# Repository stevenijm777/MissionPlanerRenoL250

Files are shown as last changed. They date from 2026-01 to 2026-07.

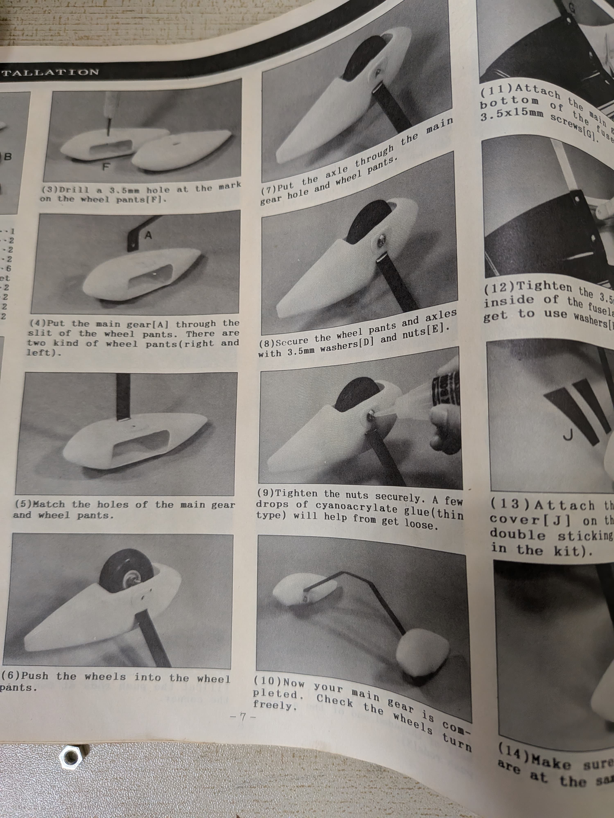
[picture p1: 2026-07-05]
Manual_RENOL250/WhatsApp Image 2025-07-14 at 20.57.17_f2a60a2f.jpg

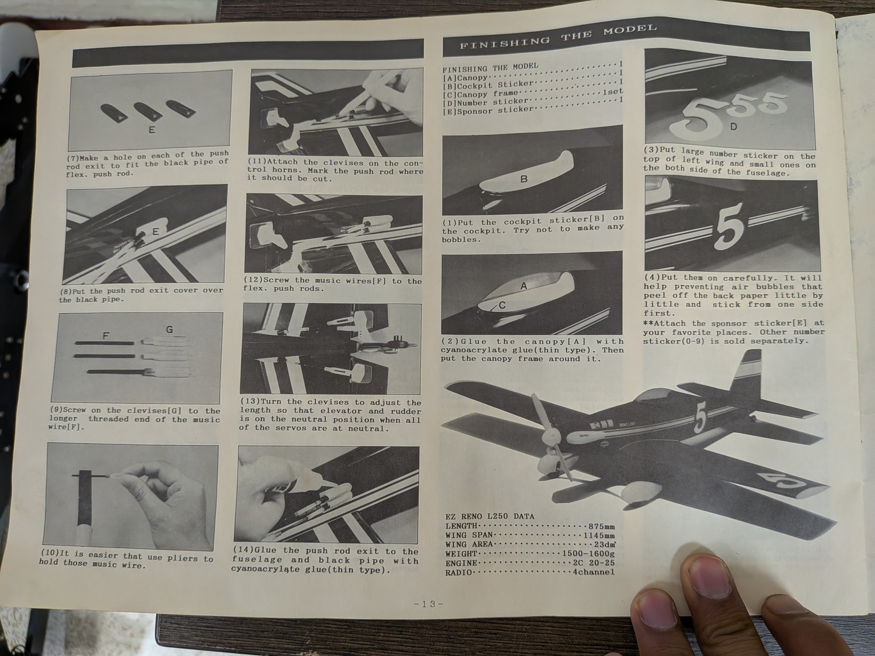
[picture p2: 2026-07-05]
Manual_RENOL250/WhatsApp Image 2025-07-14 at 20.57.13_8dc4a4ed.jpg

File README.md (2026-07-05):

# Mission Planner & Integración Mecatrónica - Reno L250 UAV

Este repositorio contiene los archivos de software, diseño mecánico CAD 3D, planos de fabricación, parámetros del piloto automático y scripts de análisis de telemetría utilizados en el proyecto de titulación y artículo de investigación: **"Integración mecatrónica y validación de una plataforma UAV de ala fija de bajo costo basada en arquitectura abierta"** (ESPOL).

El enfoque de este repositorio está orientado a la plataforma comercial **Reno L250** convertida de combustión interna a propulsión eléctrica pura para investigación en vuelo autónomo.

---

## 🔗 Repositorio de Simulación (Gemelo Digital)
Para complementar las pruebas en hardware físico con simulaciones de alta fidelidad, se ha desarrollado un Gemelo Digital en **NVIDIA Isaac Sim** empleando **Pegasus Simulator**. 
* El repositorio con el script de simulación de la planta aerodinámica y el entorno 3D está disponible en: [isaac-uav (GitHub)](https://github.com/stevenijm777/isaac-uav)
* Ruta local para contexto: `C:\Users\steve\Documents\GitRepositories\isaac-uav`

---

## 📂 Estructura del Repositorio

El repositorio se organiza de la siguiente manera:

```text
MissionPlanerRenoL250/
├── 12_Codigos_Graficas/   # Jupyter Notebook y scripts de Python para procesamiento de logs .BIN
├── Calculos/              # Hoja de cálculo verificada de diseño dinámico e importación
├── Manual_RENOL250/       # Escaneos del manual físico de ensamblaje del Reno L250
├── Modelo3D/              # Archivos CAD Autodesk Inventor (.ipt, .iam), STLs impresiones y planos PDF
├── Parametros/            # Archivos de respaldo de parámetros (.param) de ArduPilot
├── Guia_Mission_Planner.pdf # Guía de integración de software y hardware
└── .gitignore             # Configuración de exclusión para logs pesados y temporales CAD
```

### 1. `12_Codigos_Graficas/`
Contiene la algoritmia para análisis post-vuelo de telemetría y vibraciones:
* **`processVibe.py`**: Script en Python para extraer datos del mensaje `VIBE` del log de vuelo `.BIN` y generar gráficas de vibraciones en los ejes X, Y y Z en alta resolución bajo normas APA.
* **`missionPlanning.ipynb`**: Jupyter Notebook interactivo que procesa la telemetría MAVLink para validar la respuesta de actuadores comparando las entradas del piloto (`RCIN`) frente a las salidas físicas de los servomotores (`RCOUT`) en los canales de guiñada, cabeceo, alabeo y acelerador.
* **Gráficas PNG**: Resultados exportados que muestran la supresión de vibraciones y la validación de latencia cero en la cadena de control.

### 2. `Calculos/`
* **`ANALISIS_COMPLETO_UAV.xlsx`**: Hoja de cálculo dinámica y verificada que consolida el análisis de pesos (MTOW) y estimación aerodinámica de los modelos Foam Board (Manual/Auto), Reno L250 y la variante de alta velocidad (2200KV). Permite calcular de manera automática:
  * Velocidad de pérdida ($V_{stall}$) y carga alar ($WL$) basándose en el coeficiente de sustentación $C_{L_{max}}$ y área alar de diseño.
  * Relación Empuje/Peso ($T/W$) y potencia requerida.
  * Autonomía teórica y práctica (70% de reserva).
  * Desglose completo de importación (FOB EE.UU. a Ecuador sumando aranceles, Fodinfa, fletes por peso y tasas de aduana).

### 3. `Manual_RENOL250/`
* Recopilación de imágenes escaneadas de las instrucciones físicas originales del fuselaje comercial Reno L250. Esencial para conocer la distribución espacial del ala, estabilizadores, y las distancias de montaje recomendadas de fábrica.

### 4. `Modelo3D/`
* **`RenoL250/`**: Modelado 3D en Autodesk Inventor de la aeronave desglosado en ensambles (`.iam`) y partes (`.ipt`) de las alas, fuselaje principal (body), rudder, estabilizador vertical y tren de aterrizaje.
* **`Soporte_Pixhawck/`** y **`MOTOR/`**: Planos CAD de los soportes amortiguados impresos en 3D para el controlador Pixhawk 2.4.8 y el acople de conversión al motor eléctrico KingVal 3548.
* **`STL_Impresion/`**: Archivos `.stl` listos para laminación e impresión en 3D (PLA/PETG) de los soportes de servos, soportes del motor, llantas y trompa protectora.
* **`Planos_PDF_estructura/`**: Planos bidimensionales detallados con acotaciones mecánicas para la fabricación física y de taller.

### 5. `Parametros/`
* Archivos `.param` exportados desde Mission Planner. Incluyen la sintonización de lazos de control PID, límites operacionales de alabeo y cabeceo, configuración de canales PWM y calibración de sensores inerciales del UAV para ArduPilot.

---

##  Requisitos e Instalación

Para ejecutar los scripts de procesamiento de telemetría, se requiere Python 3.8+ y las siguientes dependencias:

```bash
pip install pymavlink pandas matplotlib openpyxl
```

### Ejecutar el análisis de vibraciones:
1. Copia tu archivo de log `.BIN` descargado de la tarjeta MicroSD de la Pixhawk en la carpeta de tu script.
2. Modifica la variable `log_file` en `processVibe.py` apuntando a tu archivo de log (ej. `log_file = '00000009.BIN'`).
3. Ejecuta el script:
   ```bash
   python 12_Codigos_Graficas/processVibe.py
   ```
4. Se generará una gráfica llamada `grafica_vibraciones_apa.png` mostrando la respuesta dinámica de aceleración inercial en $m/s^2$ (umbral seguro Pixhawk: $<30\text{ m/s}^2$).

---

##  Componentes de la Plataforma Reno L250 (Auto)
* **Controlador de Vuelo**: Pixhawk 2.4.8 (Firmware ArduPlane)
* **Módulo GNSS**: NEO-M8N GPS con brújula magnetómetro externa
* **Motor Brushless**: KingVal 3548 1100KV (Conversión eléctrica)
* **ESC (Speed Controller)**: Flycolor 60A ESC (3-6S Lipo)
* **Hélice**: 12x6 pulgadas de madera/nylon
* **Servomotores**: MG996R con engranajes metálicos de torque alto (3 unidades)
* **Batería**: LiPo 3S 2200 mAh (11.1 V)
* **Radiocontrol**: Transmisor Flysky FS-i6X y receptor FS-iA10B (2.4 GHz, 10 Canales)
* **Módulo de Poder (PMU)**: Sensor de corriente y regulador de voltaje 5.3V BEC

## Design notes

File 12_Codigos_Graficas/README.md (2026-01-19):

# MissionPlanerRenoL250
El código fuente para el controlador de vuelo Pixhawk, scripts de simulación y otros archivos de software se encuentran en el siguiente repositorio de GitHub.

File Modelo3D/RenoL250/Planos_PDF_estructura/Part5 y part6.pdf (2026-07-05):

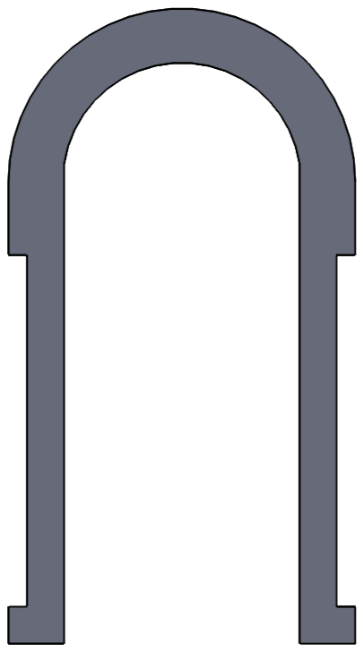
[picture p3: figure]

SOLIDWORKS Educational Product. For Instructional Use Only.

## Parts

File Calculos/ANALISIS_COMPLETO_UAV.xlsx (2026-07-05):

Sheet: DESEMPENO_UAV
ANÁLISIS DE DESEMPEÑO DE PLATAFORMAS UAV
Simbología | Características | Foam Board (Manual) | Foam Board (Auto) | Reno L250 (Auto) | Foam Board (2200KV Variant)
1. DATOS FÍSICOS Y GEOMETRÍA (ENTRADAS CAD)
b | Envergadura (m) | 1.050 m | 1.058 m | 1.143 m | 1.058 m
S | Área Alar (m²) | 0.1699 m² | 0.1699 m² | 0.2300 m² | 0.1699 m²
L | Longitud aproximada (m) | 0.800 m | 0.810 m | 0.880 m | 0.810 m
c | Cuerda media (MAC, m) | 0.155 m | 0.155 m | 0.201 m | 0.155 m
AR | Relación de Aspecto (Aspect Ratio) | 6.49 | 6.59 | 5.68 | 6.59
2. SISTEMA DE PROPULSIÓN Y BATERÍA (ENTRADAS ESPECIFICACIONES)
- | Modelo del Motor Brushless | A2212 1000KV | A2212 1000KV | KingVal 3548 1100KV | 2206 2200KV
- | Variador de velocidad (ESC) | ESC 30A | ESC 30A | ESC 60A | ESC 30A
- | Hélice seleccionada | 10x4.5 | 10x4.5 | 12x6 | 5x4.5
Vbatt | Voltaje nominal de batería (V) | 11.1 V | 11.1 V | 11.1 V | 11.1 V
C | Capacidad de la batería (Ah) | 2.2 Ah | 2.2 Ah | 2.2 Ah | 2.2 Ah
E | Energía total nominal (Wh) | 24.42 Wh | 24.42 Wh | 24.42 Wh | 24.42 Wh
Tkg | Empuje máximo estático (kg) | 0.885 kg | 0.885 kg | 2.218 kg | 1.020 kg
I_cruise | Corriente promedio en crucero (A) | 10.0 A | 10.0 A | 20.0 A | 17.0 A
I_max | Corriente en máxima aceleración (A) | 20.0 A | 20.0 A | 42.0 A | 25.0 A
I_elec | Consumo electrónica + servos (A) | 1.1 A | 1.1 A | 4.0 A | 1.1 A
3. CONSTANTES OPERATIVAS Y LÍMITES
g | Aceleración de gravedad (g, m/s²) | 9.81 m/s² | 9.81 m/s² | 9.81 m/s² | 9.81 m/s²
ρ | Densidad del aire (mar, ISA, kg/m³) | 1.225 kg/m³ | 1.225 kg/m³ | 1.225 kg/m³ | 1.225 kg/m³
CLmax | Coeficiente de Sustentación máximo | 0.90 | 0.90 | 1.20 | 0.90
CL_CFD | Coeficiente sustentación pérdida (CFD) | 0.90 | 0.90 | N/A | 0.90
4. ANÁLISIS DINÁMICO Y DESEMPEÑO CALCULADO
m | Masa total al despegue (MTOW, kg) | 0.582 kg | 0.644 kg | 1.600 kg | 0.619 kg
W | Peso total estimado (W, N) | 5.71 N | 6.32 N | 15.70 N | 6.07 N
Vstall | Velocidad de pérdida de diseño (m/s) | 7.81 m/s | 8.21 m/s | 9.64 m/s | 8.05 m/s
Vstall_k | Velocidad de pérdida de diseño (km/h) | 28.11 km/h | 29.57 km/h | 34.69 km/h | 28.99 km/h
Vstall_CFD | Velocidad de pérdida según CFD (m/s) | 7.81 m/s | 8.21 m/s | N/A | 8.05 m/s
WL | Carga Alar de Operación (g/dm²) | 34.3 g/dm² | 37.9 g/dm² | 69.6 g/dm² | 36.4 g/dm²
T/W_max | Relación Empuje/Peso Máxima | 1.52 | 1.37 | 1.39 | 1.65
t_th | Autonomía Teórica en crucero (min) | 11.9 min | 11.9 min | 5.5 min | 7.3 min
t_pr | Autonomía Práctica en crucero (70%, min) | 8.3 min | 8.3 min | 3.8 min | 5.1 min
t_th_max | Autonomía Teórica al 100% Throttle (min) | 6.3 min | 6.3 min | 2.9 min | 5.1 min
t_pr_max | Autonomía Práctica al 100% Throttle (min) | 4.4 min | 4.4 min | 2.0 min | 3.5 min
P_cruise | Potencia requerida en crucero (W) | 111.0 W | 111.0 W | 222.0 W | 188.7 W
P_max | Potencia máxima de propulsión (W) | 222.0 W | 222.0 W | 466.2 W | 277.5 W
V_cruise_rec | Velocidad de crucero recomendada (m/s) | 10.15 m/s | 10.68 m/s | 12.53 m/s | 10.47 m/s
- | Costo total importado (USD) | $234.04 | $586.62 | $1080.16 | $593.24

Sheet: MATERIALES_USA
DESGLOSE DE COSTOS Y ANÁLISIS DE IMPORTACIÓN (FOB EE.UU.)
Componente | Especificaciones | Manual Qty | W Unit Manual (g) | W Total Manual (g) | P Unit Manual (USD) | P Total Manual (USD) | Auto Qty | W Unit Auto (g) | W Total Auto (g) | P Unit Auto (USD) | P Total Auto (USD) | Reno Qty | W Unit Reno (g) | W Total Reno (g) | P Unit Reno (USD) | P Total Reno (USD) | Variant Qty | W Unit Variant (g) | W Total Variant (g) | P Unit Variant (USD) | P Total Variant (USD) | Referencia Link
Fuselaje / Estructura | Madera balsa / Foam board según plataforma | 1 | 236.00 g | 236.00 g | $8.00 | $8.00 | 1 | 166.45 g | 166.45 g | $8.00 | $8.00 | 1 | 600.00 g | 600.00 g | $260.00 | $260.00 | 1 | 166.45 g | 166.45 g | $8.00 | $8.00 | https://www.joyplanes.com/es/joytrainer-mini/
Motor Brushless | A2212 1000KV / KingVal 3548 1100KV / 2206 2200KV | 1 | 50.00 g | 50.00 g | $12.00 | $12.00 | 1 | 50.00 g | 50.00 g | $12.00 | $12.00 | 1 | 172.08 g | 172.08 g | $40.00 | $40.00 | 1 | 35.00 g | 35.00 g | $18.00 | $18.00 | https://a.co/d/4o5VnrM
Variador de Velocidad (ESC) | ESC 30A (manual/auto/variant) / Flycolor 60A (Reno) | 1 | 30.00 g | 30.00 g | $10.00 | $10.00 | 1 | 30.00 g | 30.00 g | $10.00 | $10.00 | 1 | 100.00 g | 100.00 g | $35.00 | $35.00 | 1 | 30.00 g | 30.00 g | $10.00 | $10.00 | https://www.amazon.com/dp/B09PNFKH23
Hélice de Diseño | 10x4.5 (Foam) / 12x6 (Reno) / 5x4.5 (Variant) | 1 | 15.00 g | 15.00 g | $5.00 | $5.00 | 1 | 15.00 g | 15.00 g | $5.00 | $5.00 | 1 | 40.00 g | 40.00 g | $30.00 | $30.00 | 1 | 5.00 g | 5.00 g | $4.00 | $4.00 | https://a.co/d/cJSaEcq
Batería LiPo 3S | Lipo 3S 2200 mAh (11.1 V) | 1 | 200.00 g | 200.00 g | $20.00 | $20.00 | 1 | 200.00 g | 200.00 g | $20.00 | $20.00 | 1 | 200.00 g | 200.00 g | $20.00 | $20.00 | 1 | 200.00 g | 200.00 g | $20.00 | $20.00 | https://www.amazon.com/dp/B077P73SDS
Servomotores | 9g estándar (Foam) / MG996R metal gear (Reno) | 4 | 9.00 g | 36.00 g | $2.50 | $10.00 | 4 | 9.00 g | 36.00 g | $2.50 | $10.00 | 3 | 60.00 g | 180.00 g | $10.00 | $30.00 | 4 | 9.00 g | 36.00 g | $2.50 | $10.00 | https://www.amazon.com/s?k=MG996R
Controlador de Vuelo | Pixhawk 2.4.8 Autopilot | 0 | 0.00 g | 0.00 g | $0.00 | $0.00 | 1 | 50.00 g | 50.00 g | $200.00 | $200.00 | 1 | 50.00 g | 50.00 g | $200.00 | $200.00 | 1 | 50.00 g | 50.00 g | $200.00 | $200.00 | https://www.amazon.com/dp/B07CHQ7SZ4
Módulo GPS / GNSS | NEO-M8N GPS con soporte antena | 0 | 0.00 g | 0.00 g | $0.00 | $0.00 | 1 | 20.00 g | 20.00 g | $40.00 | $40.00 | 1 | 20.00 g | 20.00 g | $40.00 | $40.00 | 1 | 20.00 g | 20.00 g | $40.00 | $40.00 | https://www.aliexpress.com/item/3256802594266311.html
Receptor Radiocontrol | Flysky FS-iA6B / FS-iA10B (2.4 GHz) | 1 | 15.00 g | 15.00 g | $24.00 | $24.00 | 1 | 15.00 g | 15.00 g | $24.00 | $24.00 | 1 | 15.00 g | 15.00 g | $24.00 | $24.00 | 1 | 15.00 g | 15.00 g | $24.00 | $24.00 | https://www.amazon.com/dp/B0744DPPL8
Transmisor Radiocontrol | Flysky FS-i6X (Estación Terrena - No embarcado) | 1 | 0.00 g | 0.00 g | $60.00 | $60.00 | 1 | 0.00 g | 0.00 g | $60.00 | $60.00 | 1 | 0.00 g | 0.00 g | $60.00 | $60.00 | 1 | 0.00 g | 0.00 g | $60.00 | $60.00 | https://www.amazon.com/dp/B0744DPPL8
Módulo de Alimentación (BEC) | Power Module 5.3V BEC con enchufe XT60 | 0 | 0.00 g | 0.00 g | $0.00 | $0.00 | 1 | 30.00 g | 30.00 g | $15.00 | $15.00 | 1 | 30.00 g | 30.00 g | $15.00 | $15.00 | 1 | 30.00 g | 30.00 g | $15.00 | $15.00 | https://www.amazon.com/dp/B06XFW1X3K
Acople impreso 3D | Soporte motor impreso PLA (en Reno) | 0 | 0.00 g | 0.00 g | $0.00 | $0.00 | 0 | 0.00 g | 0.00 g | $0.00 | $0.00 | 1 | 50.00 g | 50.00 g | $0.00 | $0.00 | 0 | 0.00 g | 0.00 g | $0.00 | $0.00 | Diseño Interno CAD (PLA)
Base interna impresa 3D | Base soporte baterías y Pixhawk (en Reno) | 0 | 0.00 g | 0.00 g | $0.00 | $0.00 | 0 | 0.00 g | 0.00 g | $0.00 | $0.00 | 1 | 80.00 g | 80.00 g | $0.00 | $0.00 | 0 | 0.00 g | 0.00 g | $0.00 | $0.00 | Diseño Interno CAD (PLA)
Otros (Tornillería, cables, velcro, pegamento, varillas) | Elementos varios para integración física | 1 | 0.00 g | 0.00 g | $0.00 | $0.00 | 1 | 31.55 g | 31.55 g | $0.00 | $0.00 | 1 | 62.92 g | 62.92 g | $0.00 | $0.00 | 1 | 272.55 g | 31.55 g | $0.00 | $0.00 | Material de taller local
SUBTOTALES (FOB EE.UU.) |  |  |  | 582.00 g |  | $149.00 |  |  | 644.00 g |  | $404.00 |  |  | 1600.00 g |  | $754.00 |  |  | 619.00 g |  | $409.00
ANÁLISIS DE COSTO DE IMPORTACIÓN A ECUADOR
Costo por Libra Courier ($/lb) |  |  |  | $5.00 |  |  |  |  | $5.00 |  |  |  |  | $5.00 |  |  |  |  | $5.00
Peso de Vuelo Total (lbs) |  |  |  | 1.28 lbs |  |  |  |  | 1.42 lbs |  |  |  |  | 3.53 lbs |  |  |  |  | 1.36 lbs
Costo por Flete (Costo Peso) |  |  |  | $6.42 |  |  |  |  | $7.10 |  |  |  |  | $17.64 |  |  |  |  | $6.82
Precio FOB en EE.UU. (USD) |  |  |  | $149.00 |  |  |  |  | $404.00 |  |  |  |  | $754.00 |  |  |  |  | $409.00
Envío Doméstico en EE.UU. (Shipping 12%) |  |  |  | $17.88 |  |  |  |  | $48.48 |  |  |  |  | $90.48 |  |  |  |  | $49.08
Impuesto Ventas EE.UU. (US Sales Tax 6%) |  |  |  | $8.94 |  |  |  |  | $24.24 |  |  |  |  | $45.24 |  |  |  |  | $24.54
Arancel de Importación (Adunas 15% FOB) |  |  |  | $22.35 |  |  |  |  | $60.60 |  |  |  |  | $113.10 |  |  |  |  | $61.35
FODINFA (5% FOB + $2.00 Fijo) |  |  |  | $9.45 |  |  |  |  | $22.20 |  |  |  |  | $39.70 |  |  |  |  | $22.45
Tasa Fija Courier (Aduana Ecu.) |  |  |  | $20.00 |  |  |  |  | $20.00 |  |  |  |  | $20.00 |  |  |  |  | $20.00
COSTO TOTAL IMPORTADO (USD) |  |  |  | $234.04 |  |  |  |  | $586.62 |  |  |  |  | $1080.16 |  |  |  |  | $593.24

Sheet: AERODINAMICA_CFD
CARACTERIZACIÓN AERODINÁMICA MEDIANTE CFD (SOLIDWORKS)
Coeficientes longitudinales del Foam Board (crucero constante V = 15 m/s, q = 137.81 Pa, S = 0.1699 m²)
Ángulo de Ataque (AoA, α) | Coeficiente Sustentación (CL) | Coeficiente Arrastre (CD) | Coeficiente Momento (Cm @ CG) | Eficiencia Aerodinámica (L/D)
0° | 0.008 | 0.155 | 0.057 | 0.05
5° | 0.245 | 0.104 | 0.039 | 2.36
10° | 0.459 | 0.128 | 0.107 | 3.59
15° | 0.719 | 0.244 | 0.119 | 2.95
20° | 0.900 | 0.367 | 0.174 | 2.45
DERIVADAS DE ESTABILIDAD Y COMPORTAMIENTO LONGITUDINAL
Pendiente de Sustentación (Linear CL_alpha) |  | CL_alpha | 2.710 rad⁻¹
Gradiente de Momento de Cabeceo (Cm_alpha) |  | Cm_alpha | -0.205 rad⁻¹
Margen Estático de Diseño (Static Margin, SM) |  | SM | #DIV/0!

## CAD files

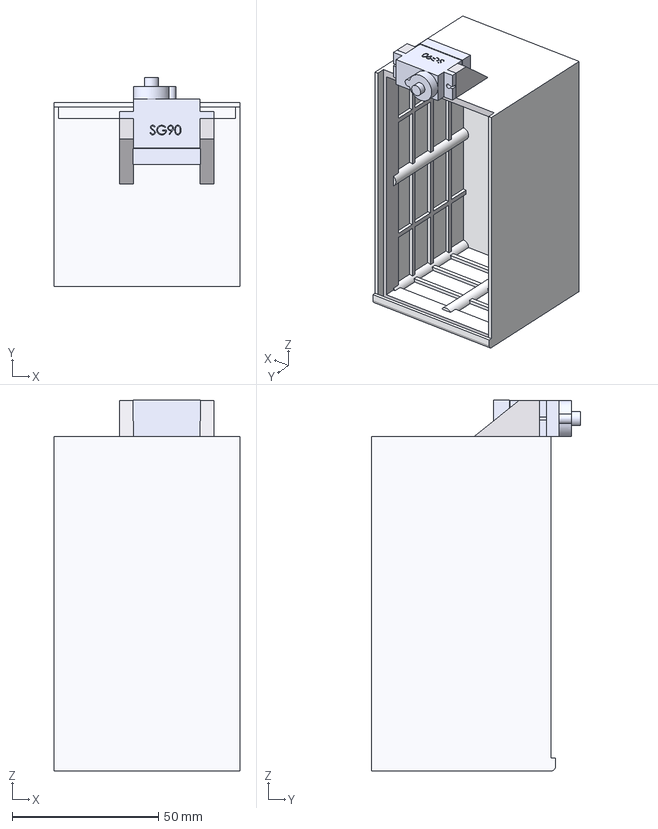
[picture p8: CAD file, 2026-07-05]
Modelo3D/Paracaidas/ParacaidasV2/Diseño de paracaidas/Diseño de paracaidas/Ensamble caja de paracaidas.stp
63.5 x 71.3 x 126.8 mm
sg90 micro servo
Caja sin ranura sin huecos

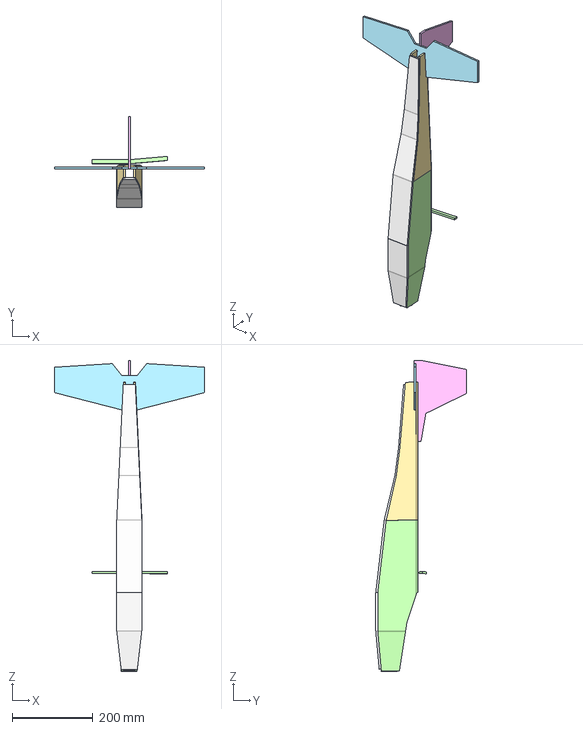
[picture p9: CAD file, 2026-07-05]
Modelo3D/CAD_SolidWorks/Avion_White/ENSAMBLE_Simplify_1.stp
372.5 x 224.1 x 770.0 mm

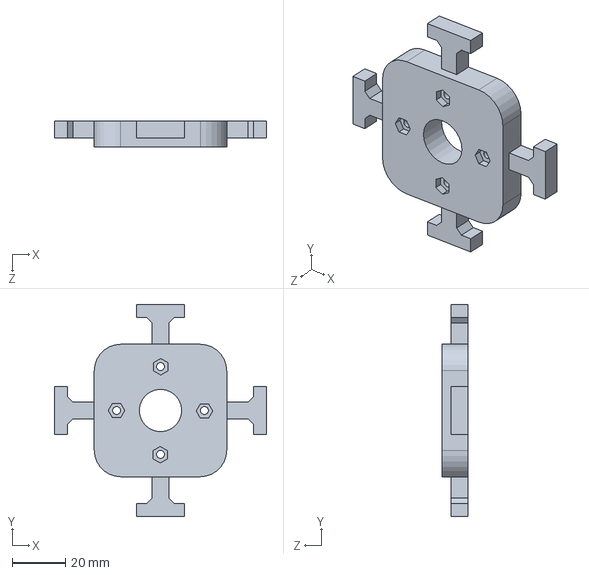
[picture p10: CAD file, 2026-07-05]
Modelo3D/CAD_SolidWorks/Avion_White/soporte_motor.SLDPRT
80.0 x 80.0 x 9.70 mm

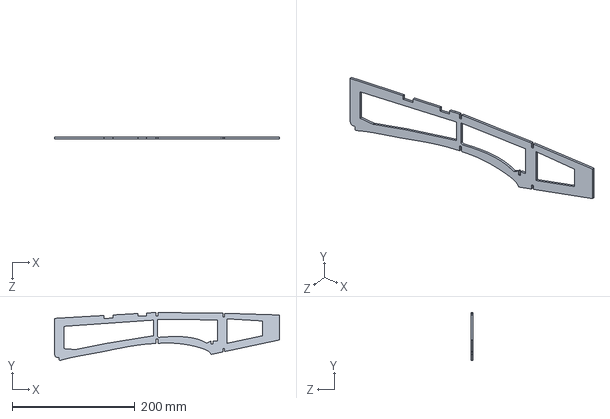
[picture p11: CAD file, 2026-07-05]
Modelo3D/CAD_SolidWorks/Piezas_Avion/fuselajev2.SLDPRT
366.8 x 78.5 x 3.00 mm

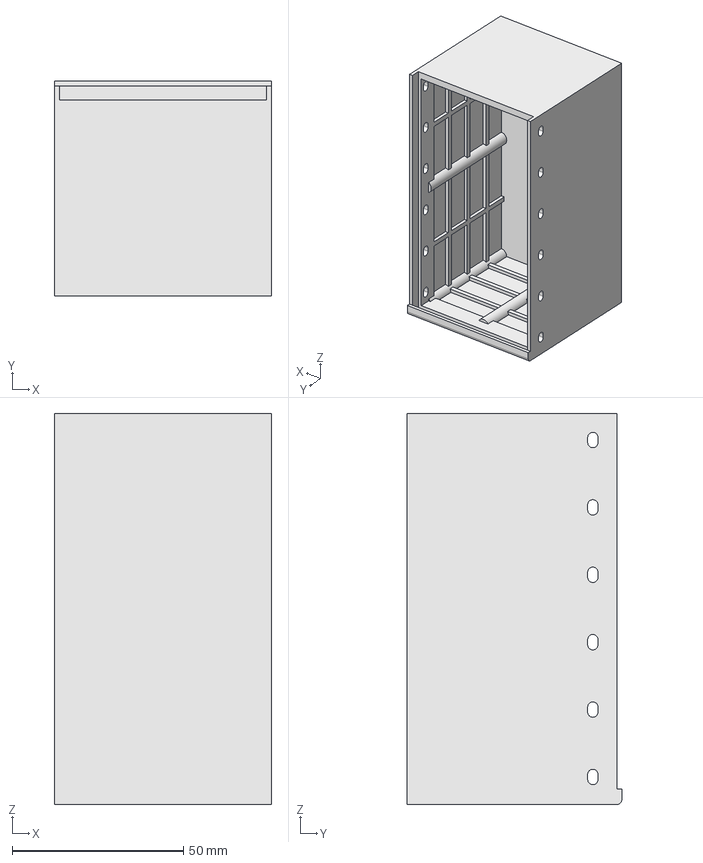
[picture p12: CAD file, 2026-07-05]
Modelo3D/Paracaidas/ParacaidasV2/Diseño de paracaidas/Diseño de paracaidas/Caja Paracaidas.stp
63.5 x 62.8 x 114.3 mm

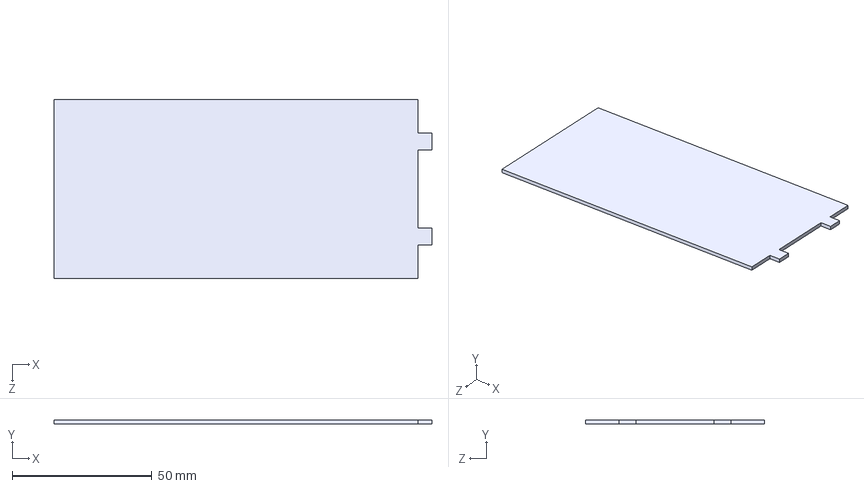
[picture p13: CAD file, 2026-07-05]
Modelo3D/Paracaidas/Tapa_Paracaidas.STEP
135.0 x 1.60 x 64.0 mm

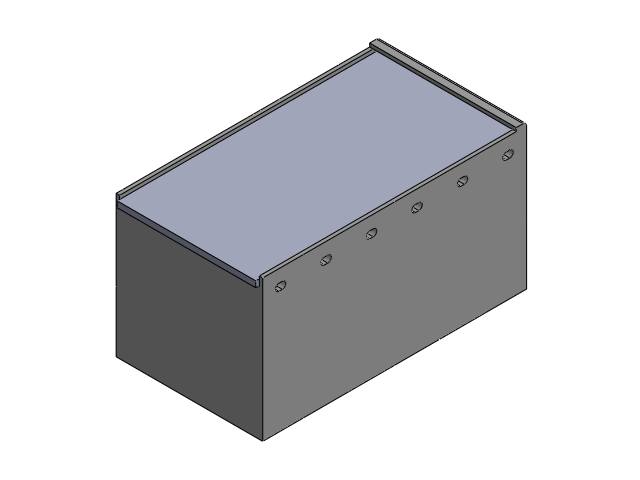
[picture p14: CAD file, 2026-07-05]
Modelo3D/Paracaidas/ParacaidasV2/Assem1.SLDASM
Caja Paracaidas
Tapa

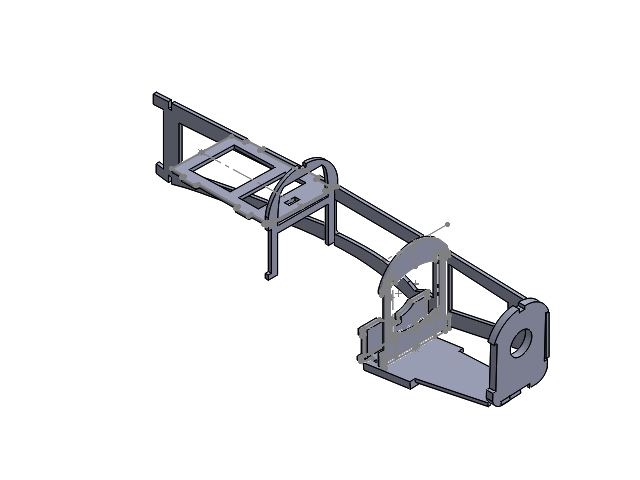
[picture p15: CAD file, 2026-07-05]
Modelo3D/CAD_SolidWorks/Piezas_Avion/esamb lev2.SLDASM
fuselajev3
soporte_servos
Soporte_motor

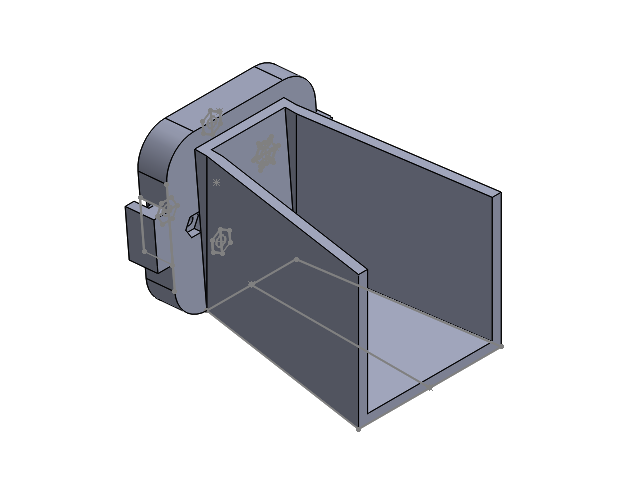
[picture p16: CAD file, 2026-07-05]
Modelo3D/CAD_SolidWorks/Avion_White/Assem1 2.SLDASM
trompa
soporte_motor_joelV2

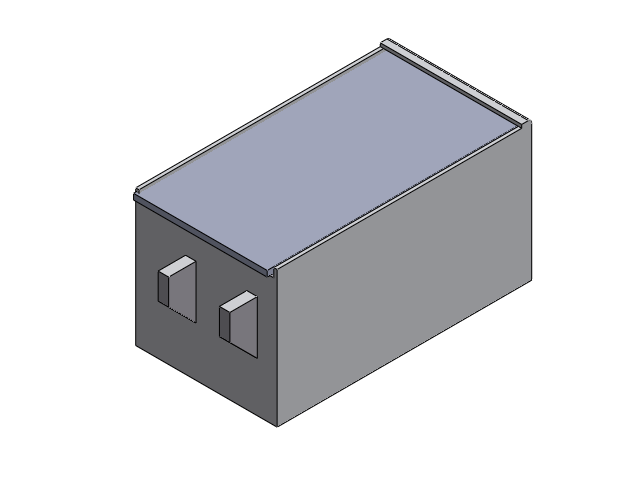
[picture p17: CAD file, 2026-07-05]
Modelo3D/Paracaidas/ParacaidasV2/Assem2.SLDASM
Caja sin ranura sin huecosV3.stp
Tapa

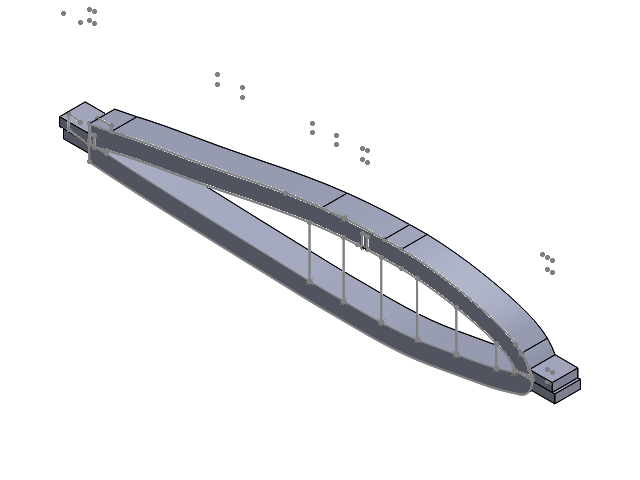
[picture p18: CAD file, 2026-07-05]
Modelo3D/CAD_SolidWorks/Piezas_Avion/esamble_Soperte.SLDASM
soporte_inferior
soporte_superior

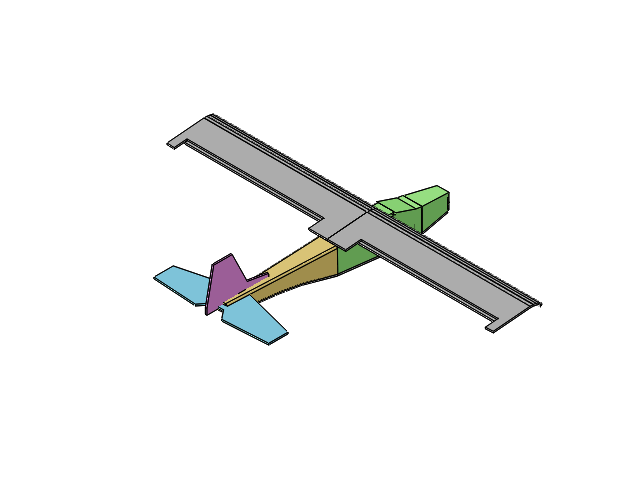
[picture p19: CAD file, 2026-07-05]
Modelo3D/CAD_SolidWorks/Avion_White/Assem1.SLDASM
ENSAMBLE_Simplify_1
ALA
ALA_MIR

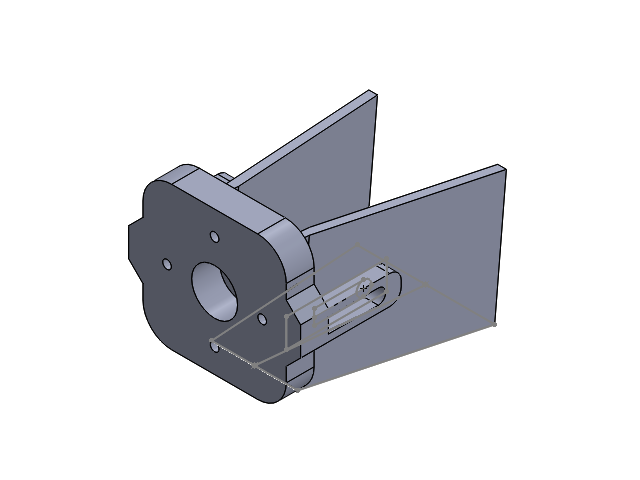
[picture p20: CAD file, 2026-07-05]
Modelo3D/CAD_SolidWorks/Avion_White/frente.SLDASM
soporte_motor_joel
trompa

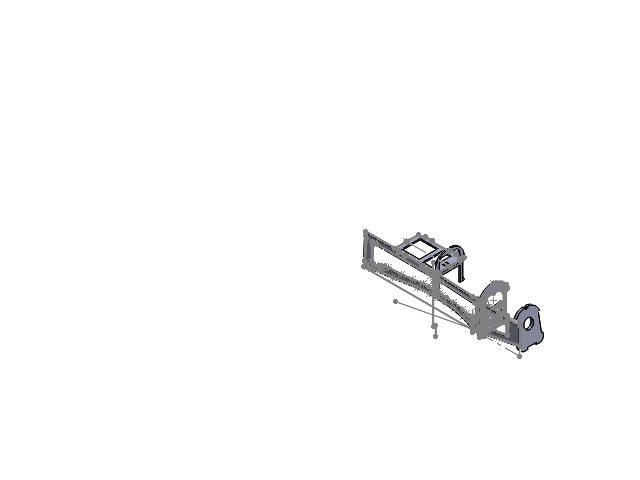
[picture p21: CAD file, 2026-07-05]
Modelo3D/CAD_SolidWorks/Piezas_Avion/esamble2.SLDASM
fuselaje
Soporte_motor
soporte_servos

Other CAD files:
Modelo3D/CAD_SolidWorks/Piezas_Avion/avion.SLDASM
Modelo3D/CAD_SolidWorks/Piezas_Avion/esmanel_soporte_agarre.SLDASM
Modelo3D/CAD_SolidWorks/Soporte_Plano.dwg
Modelo3D/Paracaidas/ParacaidasV2/Diseño de paracaidas/Diseño de paracaidas/Nueva carpeta/MARCOYCAJA.dwg
Modelo3D/CAD_SolidWorks/Avion_White/ALA.SLDPRT
Modelo3D/CAD_SolidWorks/Avion_White/ALA.stp
Modelo3D/CAD_SolidWorks/Avion_White/ALA_MIR.SLDPRT
Modelo3D/CAD_SolidWorks/Avion_White/ALA_MIR.stp
Modelo3D/CAD_SolidWorks/Avion_White/Ailerons.SLDPRT
Modelo3D/CAD_SolidWorks/Avion_White/ENSAMBLE_Simplify_1.SLDPRT
Modelo3D/CAD_SolidWorks/Avion_White/llanta_delantera.SLDPRT
Modelo3D/CAD_SolidWorks/Avion_White/llanta_trasera.SLDPRT
Modelo3D/CAD_SolidWorks/Avion_White/muelle.SLDPRT
Modelo3D/CAD_SolidWorks/Avion_White/soporte_motor_joel.SLDPRT
Modelo3D/CAD_SolidWorks/Avion_White/soporte_motor_joelV2.SLDPRT
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

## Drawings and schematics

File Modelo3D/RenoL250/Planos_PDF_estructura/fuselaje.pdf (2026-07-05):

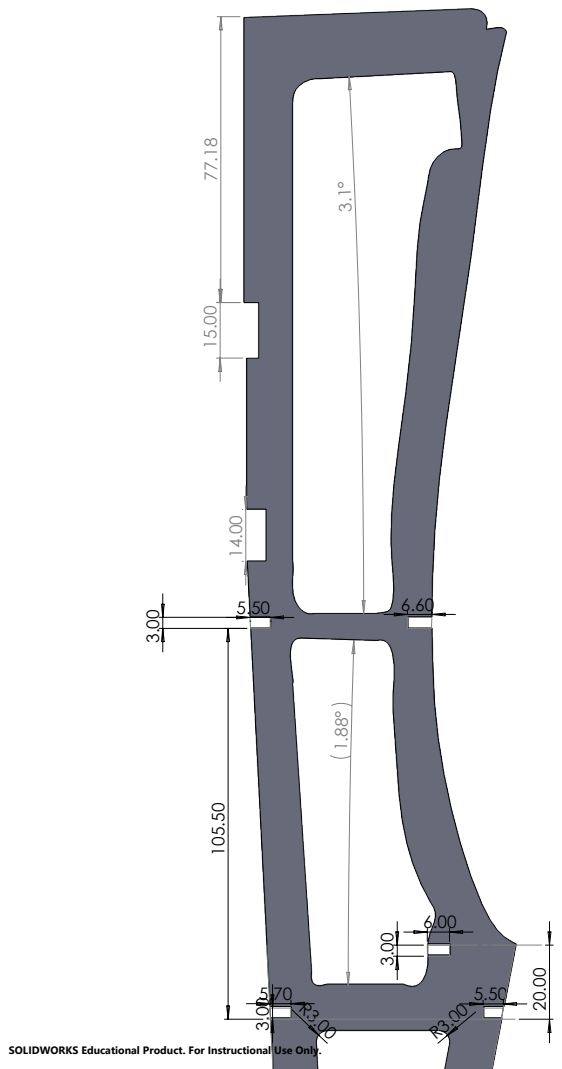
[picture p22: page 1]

SOLIDWORKS Educational Product. For Instructional Use Only.

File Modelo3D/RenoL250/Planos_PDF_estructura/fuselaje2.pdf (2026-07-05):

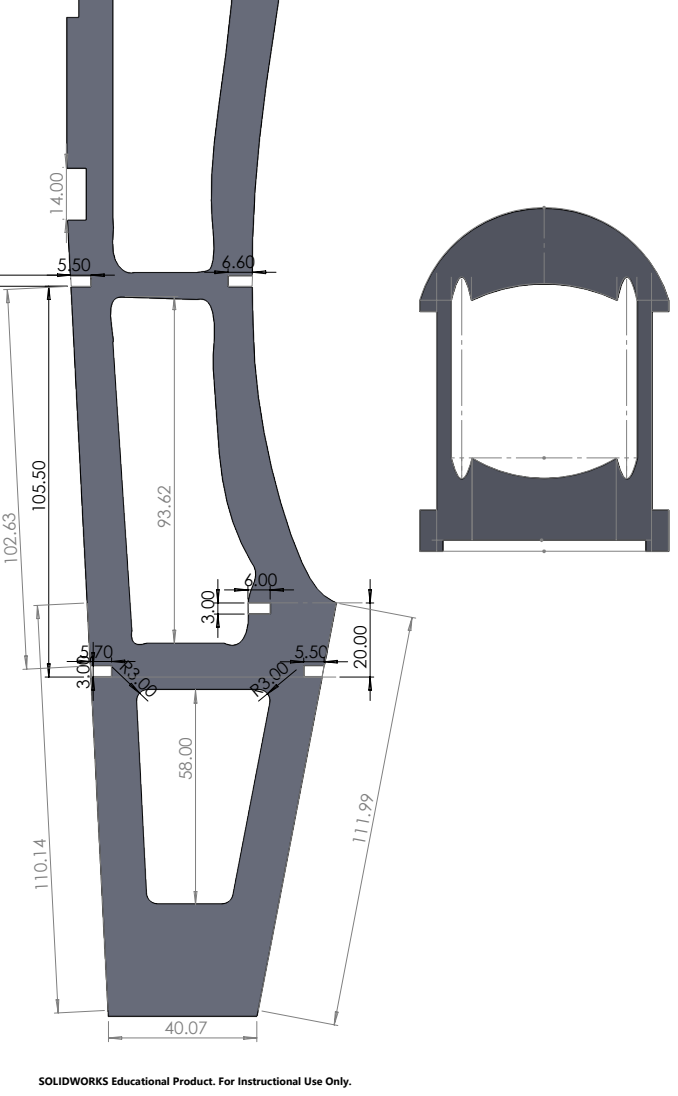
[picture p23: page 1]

SOLIDWORKS Educational Product. For Instructional Use Only.

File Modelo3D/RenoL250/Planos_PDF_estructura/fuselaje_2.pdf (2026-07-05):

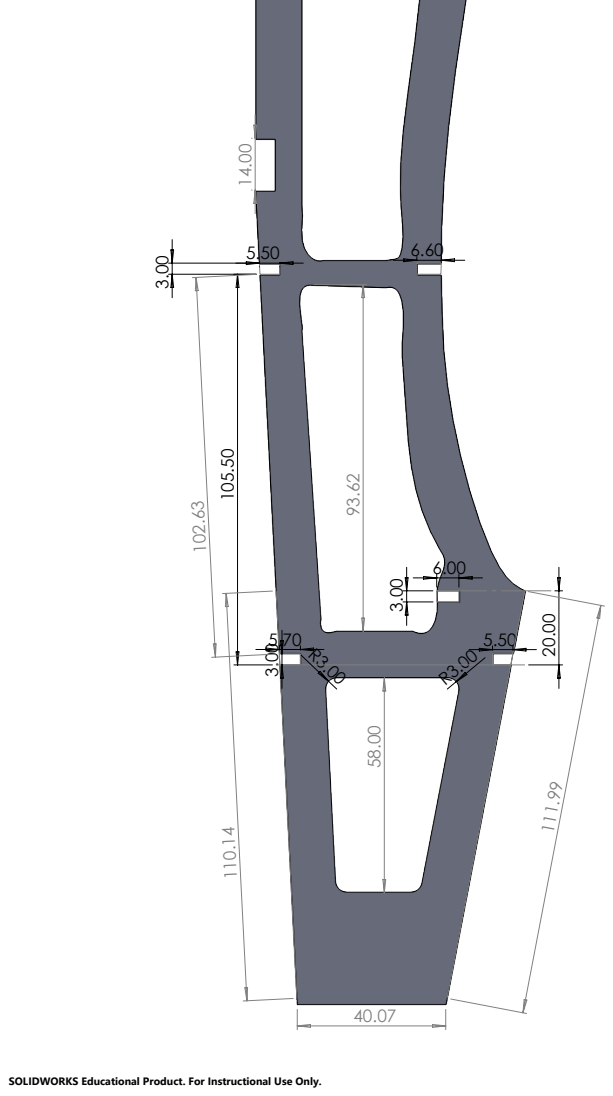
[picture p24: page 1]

SOLIDWORKS Educational Product. For Instructional Use Only.

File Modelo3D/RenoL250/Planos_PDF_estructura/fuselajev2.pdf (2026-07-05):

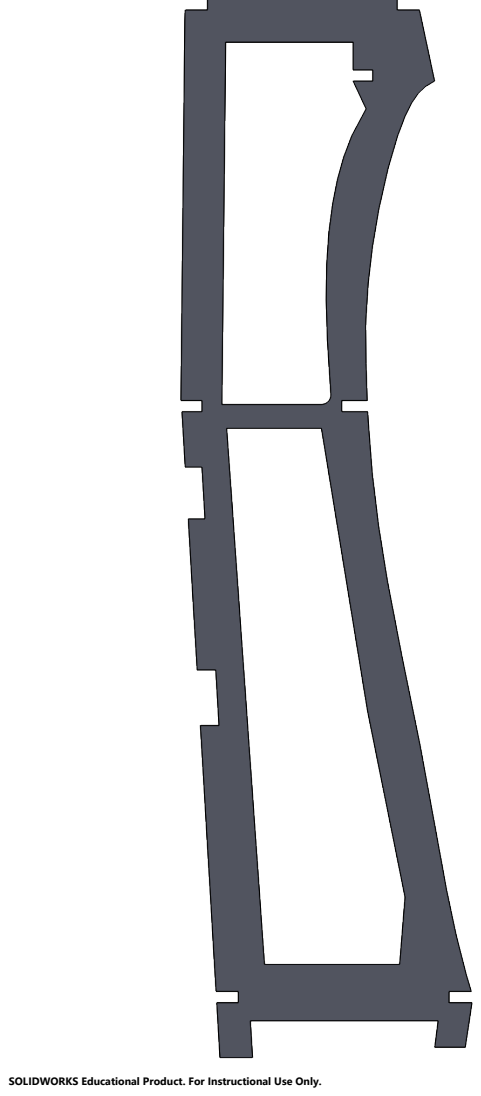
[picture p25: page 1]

SOLIDWORKS Educational Product. For Instructional Use Only.

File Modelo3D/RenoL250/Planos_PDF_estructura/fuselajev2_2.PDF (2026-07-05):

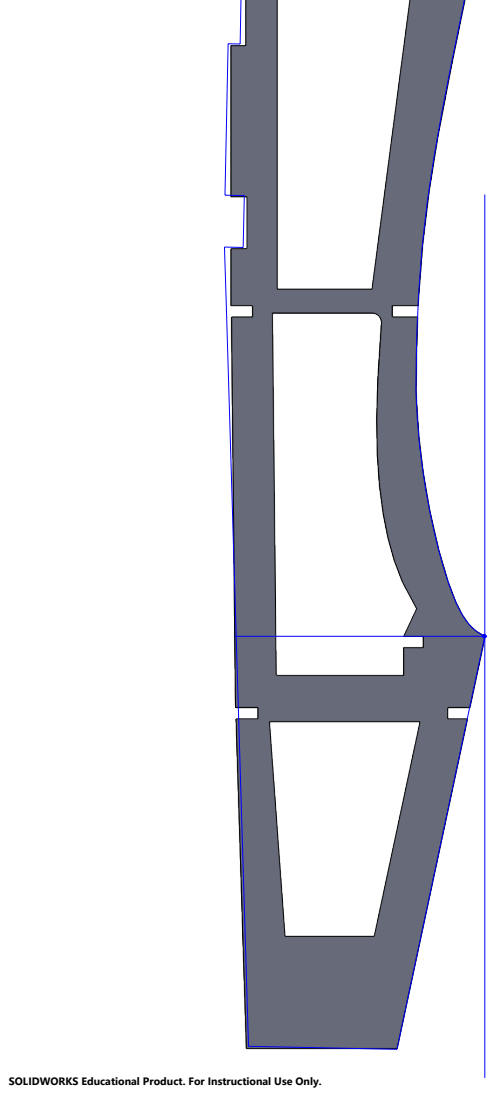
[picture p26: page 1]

SOLIDWORKS Educational Product. For Instructional Use Only.

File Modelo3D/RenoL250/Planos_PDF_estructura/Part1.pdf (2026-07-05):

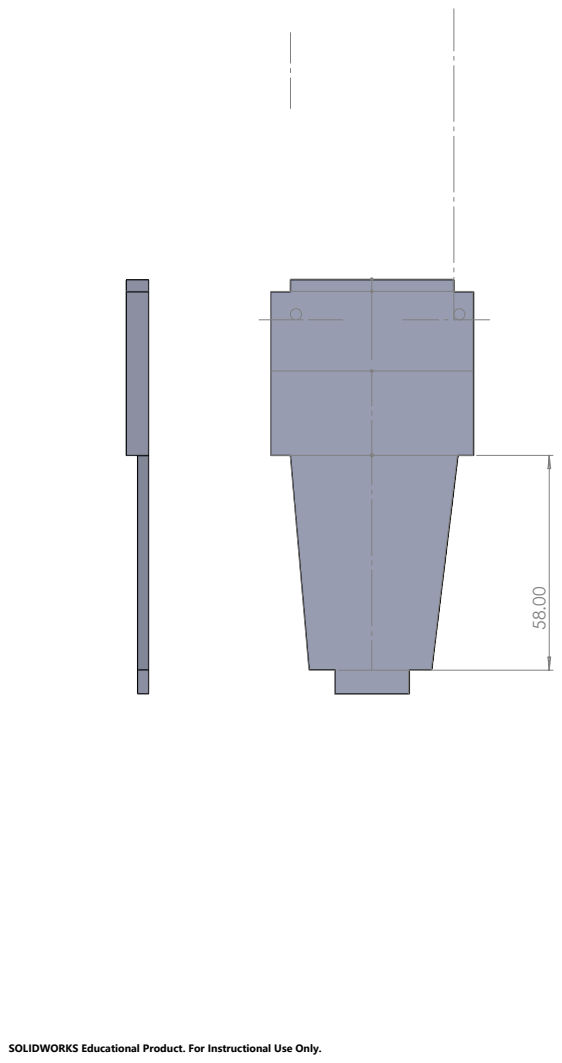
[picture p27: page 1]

SOLIDWORKS Educational Product. For Instructional Use Only.

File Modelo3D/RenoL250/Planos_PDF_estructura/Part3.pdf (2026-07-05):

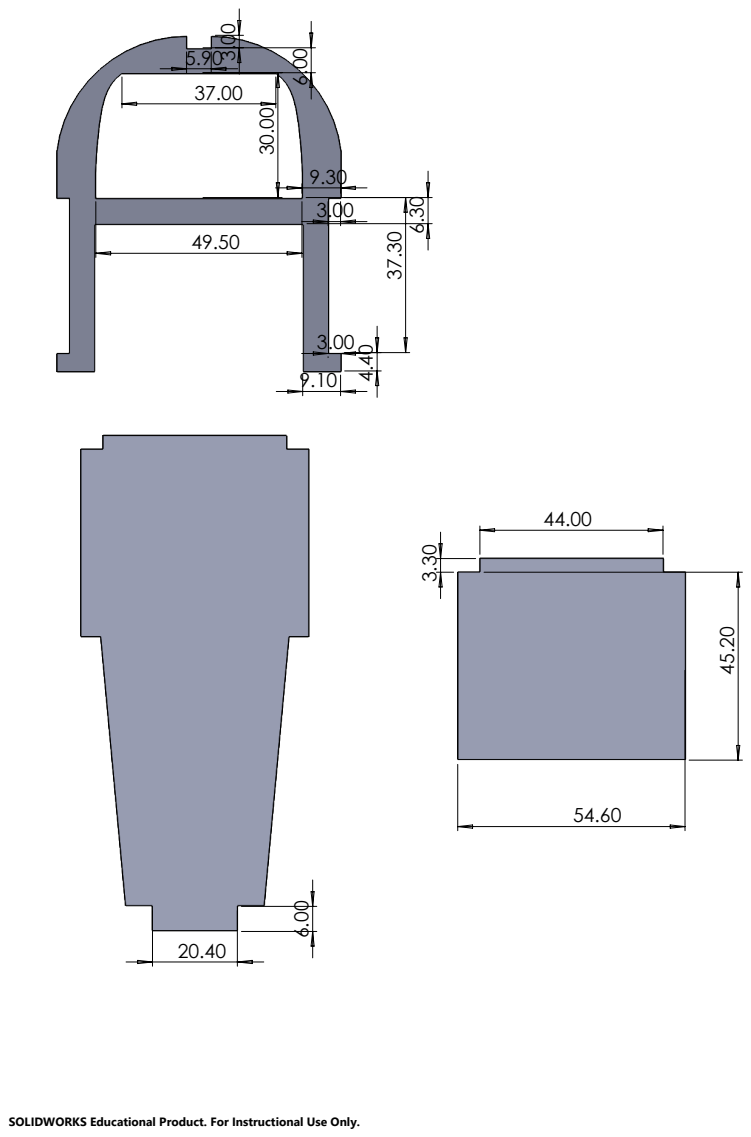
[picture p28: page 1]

SOLIDWORKS Educational Product. For Instructional Use Only.

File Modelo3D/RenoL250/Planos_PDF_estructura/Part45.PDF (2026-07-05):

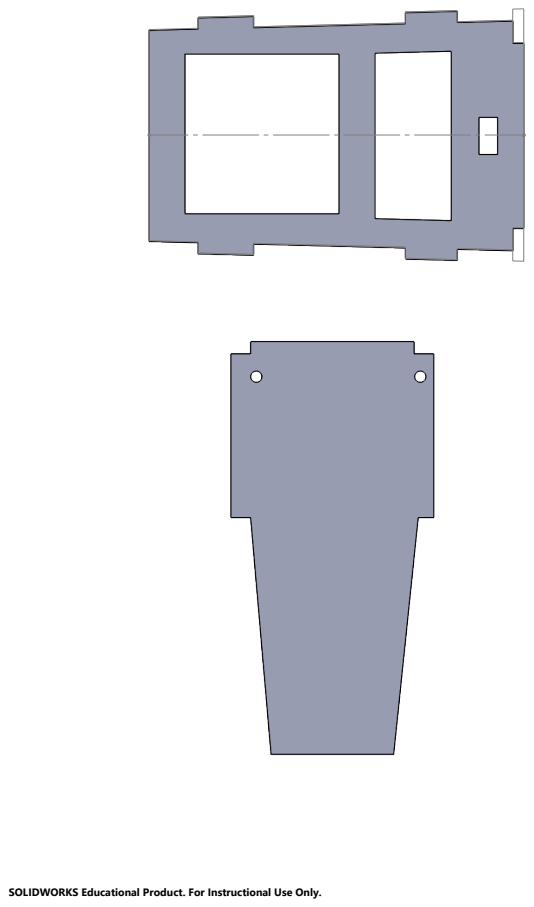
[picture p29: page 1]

SOLIDWORKS Educational Product. For Instructional Use Only.

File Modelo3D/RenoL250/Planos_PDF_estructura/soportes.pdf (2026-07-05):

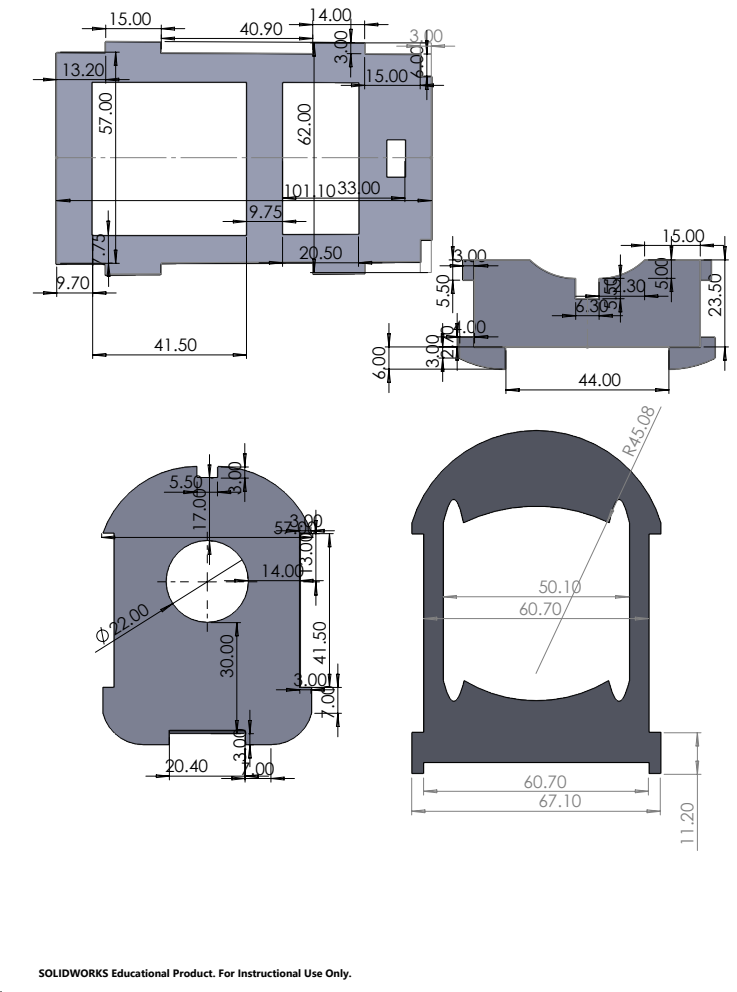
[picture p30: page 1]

SOLIDWORKS Educational Product. For Instructional Use Only.

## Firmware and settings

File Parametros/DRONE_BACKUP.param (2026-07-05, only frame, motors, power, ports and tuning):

ATC_ANG_LIM_TC,1
ATC_ANG_PIT_P,4.5
ATC_ANG_RLL_P,4.5
ATC_ANG_YAW_P,4.5
ATC_ANGLE_BOOST,1
ATC_RAT_PIT_D,0.0036
ATC_RAT_PIT_D_FF,0
ATC_RAT_PIT_FF,0
ATC_RAT_PIT_FLTD,23
ATC_RAT_PIT_FLTE,0
ATC_RAT_PIT_FLTT,23
ATC_RAT_PIT_I,0.135
ATC_RAT_PIT_IMAX,0.5
ATC_RAT_PIT_P,0.135
ATC_RAT_PIT_PDMX,0
ATC_RAT_PIT_SMAX,0
ATC_RAT_RLL_D,0.0036
ATC_RAT_RLL_D_FF,0
ATC_RAT_RLL_FF,0
ATC_RAT_RLL_FLTD,23
ATC_RAT_RLL_FLTE,0
ATC_RAT_RLL_FLTT,23
ATC_RAT_RLL_I,0.135
ATC_RAT_RLL_IMAX,0.5
ATC_RAT_RLL_P,0.135
ATC_RAT_RLL_PDMX,0
ATC_RAT_RLL_SMAX,0
ATC_RAT_YAW_D,0
ATC_RAT_YAW_D_FF,0
ATC_RAT_YAW_FF,0
ATC_RAT_YAW_FLTD,0
ATC_RAT_YAW_FLTE,2
ATC_RAT_YAW_FLTT,23
ATC_RAT_YAW_I,0.018
ATC_RAT_YAW_IMAX,0.5
ATC_RAT_YAW_P,0.18
ATC_RAT_YAW_PDMX,0
ATC_RAT_YAW_SMAX,0
ATC_RATE_FF_ENAB,1
ATC_RATE_P_MAX,0
ATC_RATE_R_MAX,0
ATC_RATE_Y_MAX,0
BATT_AMP_OFFSET,0
BATT_AMP_PERVLT,17
BATT_ARM_MAH,0
BATT_ARM_VOLT,0
BATT_CAPACITY,3300
BATT_CRT_MAH,0
BATT_CRT_VOLT,0
BATT_CURR_PIN,3
BATT_FS_CRT_ACT,0
BATT_FS_LOW_ACT,0
BATT_FS_VOLTSRC,0
BATT_LOW_MAH,0
BATT_LOW_TIMER,10
BATT_LOW_VOLT,10.5
BATT_MONITOR,4
BATT_OPTIONS,0
BATT_SERIAL_NUM,-1
BATT_VLT_OFFSET,0
BATT_VOLT_MULT,10.1
BATT_VOLT_PIN,2
BATT2_MONITOR,0
BATT3_MONITOR,0
BATT4_MONITOR,0
BATT5_MONITOR,0
BATT6_MONITOR,0
BATT7_MONITOR,0
BATT8_MONITOR,0
BATT9_MONITOR,0
FLTMODE_CH,5
FLTMODE_GCSBLOCK,0
FLTMODE1,0
FLTMODE2,0
FLTMODE3,6
FLTMODE4,2
FLTMODE5,0
FLTMODE6,9
FRAME_CLASS,1
FRAME_TYPE,1
INS_GYRO_FILTER,46
INS_HNTCH_ENABLE,0
MOT_BAT_CURR_MAX,0
MOT_BAT_CURR_TC,5
MOT_BAT_IDX,0
MOT_BAT_VOLT_MAX,16.8
MOT_BAT_VOLT_MIN,13.2
MOT_BOOST_SCALE,0
MOT_HOVER_LEARN,2
MOT_OPTIONS,0
MOT_PWM_MAX,1989
MOT_PWM_MIN,1000
MOT_PWM_TYPE,0
MOT_SAFE_DISARM,0
MOT_SAFE_TIME,1
MOT_SLEW_DN_TIME,0
MOT_SLEW_UP_TIME,0
MOT_SPIN_ARM,0.1
MOT_SPIN_MAX,0.95
MOT_SPIN_MIN,0.15
MOT_SPOOL_TIM_DN,0
MOT_SPOOL_TIME,0.5
MOT_THST_EXPO,0.65
MOT_THST_HOVER,0.3080127
MOT_YAW_HEADROOM,200
SERIAL0_BAUD,115
SERIAL0_PROTOCOL,2
SERIAL1_BAUD,57
SERIAL1_OPTIONS,0
SERIAL1_PROTOCOL,2
SERIAL2_BAUD,57
SERIAL2_OPTIONS,0
SERIAL2_PROTOCOL,2
SERIAL3_BAUD,38
SERIAL3_OPTIONS,0
SERIAL3_PROTOCOL,5
SERIAL4_BAUD,230
SERIAL4_OPTIONS,0
SERIAL4_PROTOCOL,5
SERIAL5_BAUD,57
SERIAL5_OPTIONS,0
SERIAL5_PROTOCOL,-1
SERVO1_FUNCTION,33
SERVO1_MAX,1900
SERVO1_MIN,1000
SERVO1_REVERSED,0
SERVO1_TRIM,1200
SERVO2_FUNCTION,34
SERVO2_MAX,1900
SERVO2_MIN,1000
SERVO2_REVERSED,0
SERVO2_TRIM,1200
SERVO3_FUNCTION,35
SERVO3_MAX,1900
SERVO3_MIN,1000
SERVO3_REVERSED,0
SERVO3_TRIM,1200
SERVO4_FUNCTION,36
SERVO4_MAX,1900
SERVO4_MIN,1000
SERVO4_REVERSED,0
SERVO4_TRIM,1200
SERVO5_FUNCTION,0
SERVO5_MAX,1900
SERVO5_MIN,1100
SERVO5_REVERSED,0
SERVO5_TRIM,1500
SERVO6_FUNCTION,0
SERVO6_MAX,1900
SERVO6_MIN,1100
SERVO6_REVERSED,0
SERVO6_TRIM,1500
SERVO7_FUNCTION,0
SERVO7_MAX,1900
SERVO7_MIN,1100
SERVO7_REVERSED,0
SERVO7_TRIM,1500
SERVO8_FUNCTION,0
SERVO8_MAX,1900
SERVO8_MIN,1100
SERVO8_REVERSED,0
SERVO8_TRIM,1500
SERVO9_FUNCTION,1
SERVO9_MAX,1900
SERVO9_MIN,1100
SERVO9_REVERSED,0
SERVO9_TRIM,1500

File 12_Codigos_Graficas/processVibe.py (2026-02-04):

from pymavlink import mavutil
import pandas as pd
import matplotlib.pyplot as plt

# --- CONFIGURACIÓN ---
# Reemplaza con la ruta a tu archivo .BIN descargado del Pixhawk
log_file = 'ruta/a/tu/log_de_vuelo.BIN' 

# Conectar con el log
print(f"Leyendo log: {log_file}...")
mlog = mavutil.mavlink_connection(log_file)

# Listas para almacenar datos
data = {'TimeUS': [], 'VibeX': [], 'VibeY': [], 'VibeZ': [], 'Clip0': []}

# --- EXTRACCIÓN DE DATOS ---
while True:
    msg = mlog.recv_match(type='VIBE', blocking=False)
    if not msg:
        break
    
    # Extraer datos del mensaje VIBE
    data['TimeUS'].append(msg.TimeUS)
    data['VibeX'].append(msg.VibeX)
    data['VibeY'].append(msg.VibeY)
    data['VibeZ'].append(msg.VibeZ)
    data['Clip0'].append(msg.Clip0)

# Crear DataFrame
df = pd.DataFrame(data)
# Convertir tiempo a segundos (TimeUS está en microsegundos desde el arranque)
df['TimeSec'] = (df['TimeUS'] - df['TimeUS'].iloc[0]) / 1e6

# --- GRAFICACIÓN (Estilo APA / Académico) ---
# Norma APA sugiere fuentes sans-serif (Arial, Calibri) dentro de figuras 
plt.rcParams['font.family'] = 'sans-serif'
plt.rcParams['font.sans-serif'] = ['Arial']

fig, ax = plt.subplots(figsize=(10, 6))

# Graficar Vibraciones
ax.plot(df['TimeSec'], df['VibeX'], label='Vibe X', linewidth=1)
ax.plot(df['TimeSec'], df['VibeY'], label='Vibe Y', linewidth=1)
ax.plot(df['TimeSec'], df['VibeZ'], label='Vibe Z', linewidth=1)

# Configuración de ejes y etiquetas
ax.set_xlabel('Tiempo (segundos)', fontsize=11, fontweight='bold')
ax.set_ylabel('Vibración (m/s²)', fontsize=11, fontweight='bold')
ax.set_title('Análisis de Vibraciones durante el Vuelo', fontsize=12, style='italic') # Título descriptivo [cite: 1608]
ax.legend()
ax.grid(True, linestyle='--', alpha=0.7)

# Guardar en alta resolución
plt.savefig('grafica_vibraciones_apa.png', dpi=300, bbox_inches='tight')
plt.show()

print("Gráfica generada exitosamente.")

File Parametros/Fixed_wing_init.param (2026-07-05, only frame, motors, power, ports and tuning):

BATT_MONITOR,0
BATT2_MONITOR,0
BATT3_MONITOR,0
BATT4_MONITOR,0
BATT5_MONITOR,0
BATT6_MONITOR,0
BATT7_MONITOR,0
BATT8_MONITOR,0
BATT9_MONITOR,0
FLTMODE_CH,8
FLTMODE_GCSBLOCK,0
FLTMODE1,11
FLTMODE2,11
FLTMODE3,5
FLTMODE4,5
FLTMODE5,0
FLTMODE6,0
INS_GYRO_FILTER,20
INS_HNTCH_ENABLE,0
SERIAL0_BAUD,115
SERIAL0_PROTOCOL,2
SERIAL1_BAUD,57
SERIAL1_OPTIONS,0
SERIAL1_PROTOCOL,2
SERIAL2_BAUD,57
SERIAL2_OPTIONS,0
SERIAL2_PROTOCOL,2
SERIAL3_BAUD,230
SERIAL3_OPTIONS,0
SERIAL3_PROTOCOL,5
SERIAL4_BAUD,230
SERIAL4_OPTIONS,0
SERIAL4_PROTOCOL,5
SERIAL5_BAUD,57
SERIAL5_OPTIONS,0
SERIAL5_PROTOCOL,-1
SERVO1_FUNCTION,4
SERVO1_MAX,1900
SERVO1_MIN,1100
SERVO1_REVERSED,0
SERVO1_TRIM,1500
SERVO2_FUNCTION,19
SERVO2_MAX,1900
SERVO2_MIN,1100
SERVO2_REVERSED,0
SERVO2_TRIM,1500
SERVO3_FUNCTION,70
SERVO3_MAX,1900
SERVO3_MIN,1100
SERVO3_REVERSED,0
SERVO3_TRIM,1100
SERVO4_FUNCTION,21
SERVO4_MAX,1900
SERVO4_MIN,1100
SERVO4_REVERSED,0
SERVO4_TRIM,1500
SERVO5_FUNCTION,0
SERVO5_MAX,1900
SERVO5_MIN,1100
SERVO5_REVERSED,0
SERVO5_TRIM,1500
SERVO6_FUNCTION,0
SERVO6_MAX,1900
SERVO6_MIN,1100
SERVO6_REVERSED,0
SERVO6_TRIM,1500
SERVO7_FUNCTION,0
SERVO7_MAX,1900
SERVO7_MIN,1100
SERVO7_REVERSED,0
SERVO7_TRIM,1500
SERVO8_FUNCTION,0
SERVO8_MAX,1900
SERVO8_MIN,1100
SERVO8_REVERSED,0
SERVO8_TRIM,1500
SERVO9_FUNCTION,0
SERVO9_MAX,1900
SERVO9_MIN,1100
SERVO9_REVERSED,0
SERVO9_TRIM,1500

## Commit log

2026-07-05 final edition
    [7mm motor mount PART1 (edited).ipt, 7mm motor mount PART2 (draft2).ipt, A-MainGear.ipt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]
2026-07-05 Update Analisis_UAV
    [ANALISIS_COMPLETO_UAV.xlsx]
